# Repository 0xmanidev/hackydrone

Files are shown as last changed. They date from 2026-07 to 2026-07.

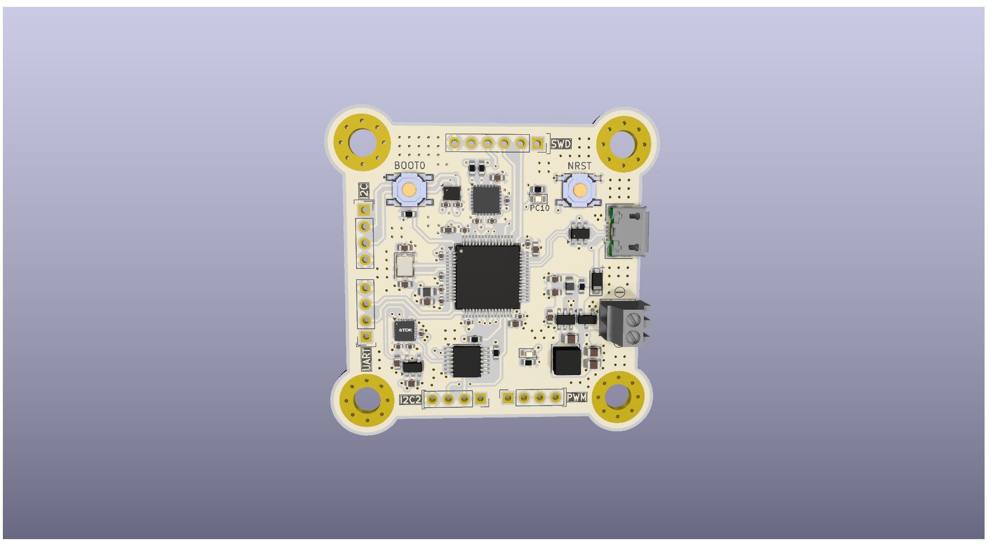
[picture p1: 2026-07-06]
pcb/flight-controller/images/pcb-front.png

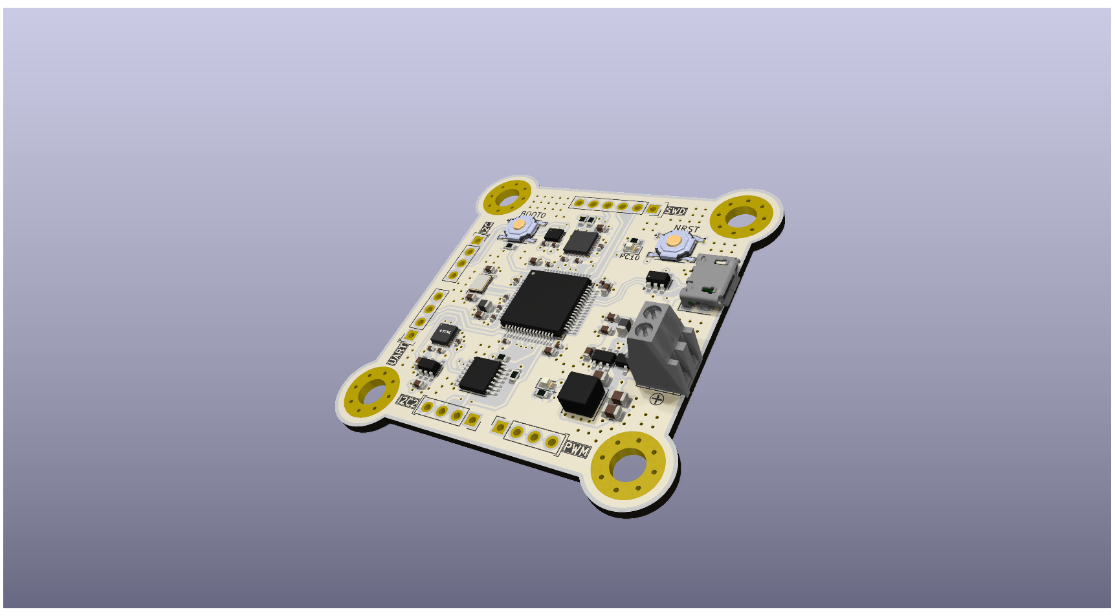
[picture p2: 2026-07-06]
pcb/flight-controller/images/pcb.png

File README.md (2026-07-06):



# HACKYDRONE
This is my project for Outpost. It's an F450-style drone with a custom-designed frame, a custom flight controller, and a strong focus on keeping costs low without sacrificing performance. The drone runs Betaflight firmware and uses a SpeedyBee ESC for reliable motor control.

This project is built with the help of Hackclub and the program submitted to
[Outpost](https://outpost.hackclub.com/) / [Stardance](https://stardance.hackclub.com/)



# Building

Clone the repository:

```bash
git clone https://github.com/0xmanidev/hackydrone.git

cd hackydrone
```

Compile firmware:

```bash
cd firmware/betaflight-2025.12.5

make TARGET=<BOARD_NAME>
```

---
## PCB

The `pcb/` directory contains everything required to manufacture the custom flight controller.

Included files:

- Complete KiCad project
- Bill of Materials (BOM)
- IPC netlist
- Manufacturing outputs

These files can be directly submitted to PCB fabrication services.


for more accurate and interactive schematics view the pcb/flight-controller -flight-controller.kicad_Sch,sensor.kicad_sch

---
# 3d model
3d-mockup

# Flight controller
pcb



# Components(these are the only after market components)
<div align="center">



</div>

---

# Current Status

| Component | Status |
|---|---|
| Frame Design | ✅ Complete |
| Flight Controller PCB | ✅ Complete |
| Firmware | ✅ Working |
| CAD Models | ✅ Complete |
| PCB Manufacturing Files | ✅ Included |
| Flight Testing | 🚧 In Progress |

---
# References

## STM32F405RGTx Microcontroller
- Datasheet:
  https://www.st.com/resource/en/datasheet/stm32f405rg.pdf
- Reference Manual (RM0090):
  https://www.st.com/resource/en/reference_manual/dm00031020.pdf
- Programming Manual:
  https://www.st.com/resource/en/programming_manual/dm00046982.pdf

---

## MPU-6050 6-Axis IMU
- Product Specification:
  https://invensense.tdk.com/wp-content/uploads/2015/02/MPU-6000-Datasheet1.pdf
- Register Map:
  https://invensense.tdk.com/wp-content/uploads/2015/02/MPU-6000-Register-Map1.pdf

---

## ICM-20948 9-Axis IMU
- Datasheet:
  https://invensense.tdk.com/wp-content/uploads/2024/03/DS-000189-ICM-20948-v1.6.pdf
- Register Map:
  https://invensense.tdk.com/wp-content/uploads/2024/03/RM-000189-ICM-20948-v1.3.pdf

---

## BMP280 Barometric Pressure Sensor
- Datasheet:
  https://cdn-shop.adafruit.com/datasheets/BST-BMP280-DS001-11.pdf

---

## AP63303WU 3A Buck Converter
- Datasheet:
  https://www.diodes.com/assets/Datasheets/AP63303_AP63357.pdf

---

## USBLC6-2SC6 USB ESD Protection
- Datasheet:
  https://www.st.com/resource/en/datasheet/usblc6-2.pdf

---

## LD39015M18R 1.8V Low Dropout Regulator
- Datasheet:
  https://www.st.com/resource/en/datasheet/ld39015.pdf

---

## NTS0104PW 4-bit Voltage Level Translator
- Datasheet:
  https://assets.nexperia.com/documents/data-sheet/NTS0104.pdf

---

## AO3401A P-Channel MOSFET
- Datasheet:
  https://aosmd.com/res/data_sheets/AO3401A.pdf

---

## TS-1187A Push Button Switch
- Datasheet:
  https://www.ckswitches.com/media/1457/ts.pdf

---

## 16 MHz Crystal Oscillator
- Example Reference (Abracon):
  https://abracon.com/Resonators/ABM3.pdf

---

## Micro USB Connector
- USB 2.0 Specification:
  https://www.usb.org/document-library/usb-20-specification

---

# Design References

- STMicroelectronics AN4488 – Getting Started with STM32F4 Hardware Development
  https://www.st.com/resource/en/application_note/dm00077036.pdf

- AN2867 – Oscillator Design Guide for STM32 Microcontrollers
  https://www.st.com/resource/en/application_note/cd00221665.pdf

- UM10204 – I²C-bus Specification and User Manual
  https://www.nxp.com/docs/en/user-guide/UM10204.pdf

- USB 2.0 Specification
  https://www.usb.org/document-library/usb-20-specification
AI USAGE : RESEARCH purposes and for mockups and visuals 

# credits : hackclub community - stasis community for helping out in making and outpost team for staying active and resolving queries
MADE with love by 0xmanidev

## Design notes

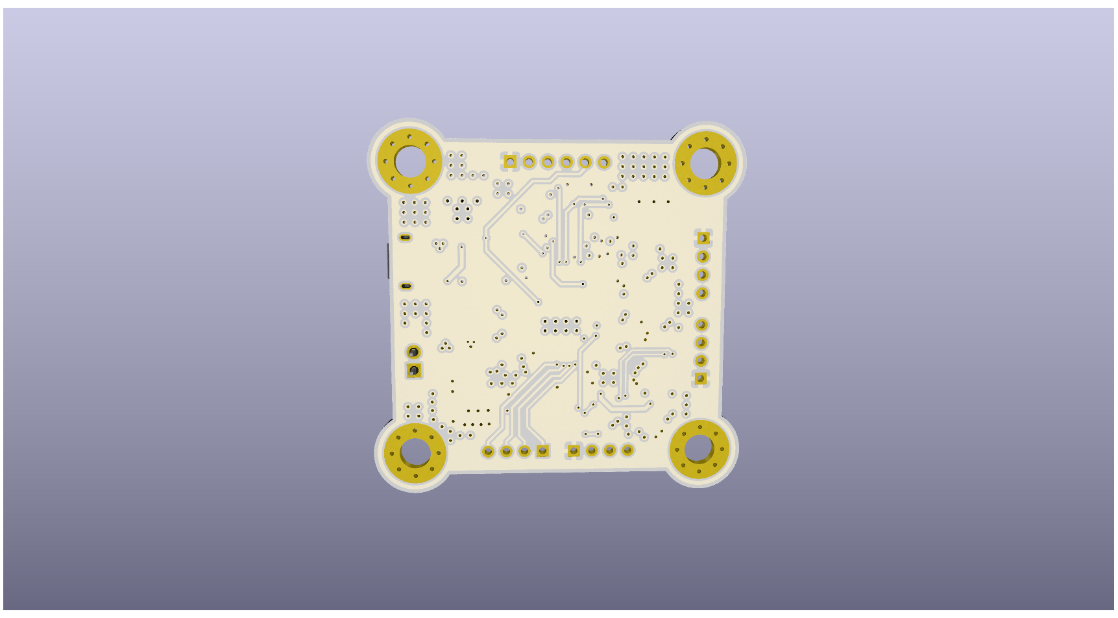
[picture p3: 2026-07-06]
pcb/flight-controller/images/pcb-back.png

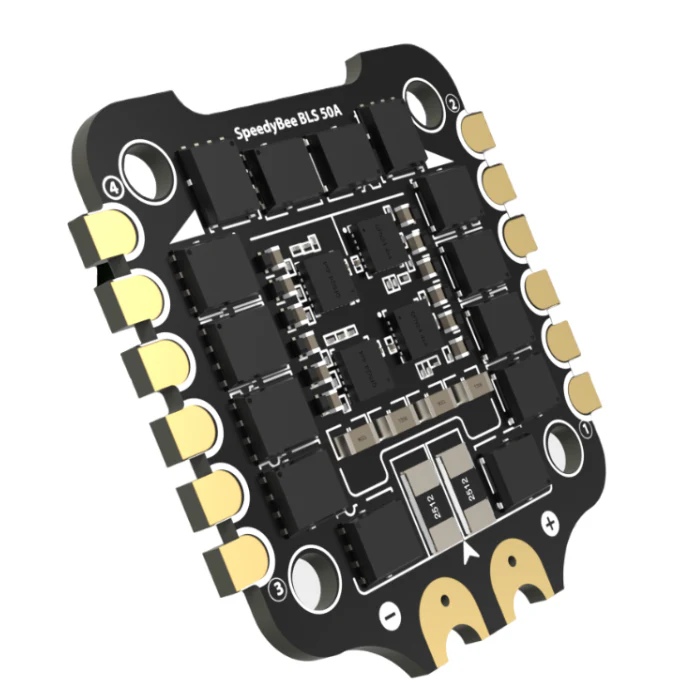
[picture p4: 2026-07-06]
pcb/ESC(only-info)/ESC-tilted.png

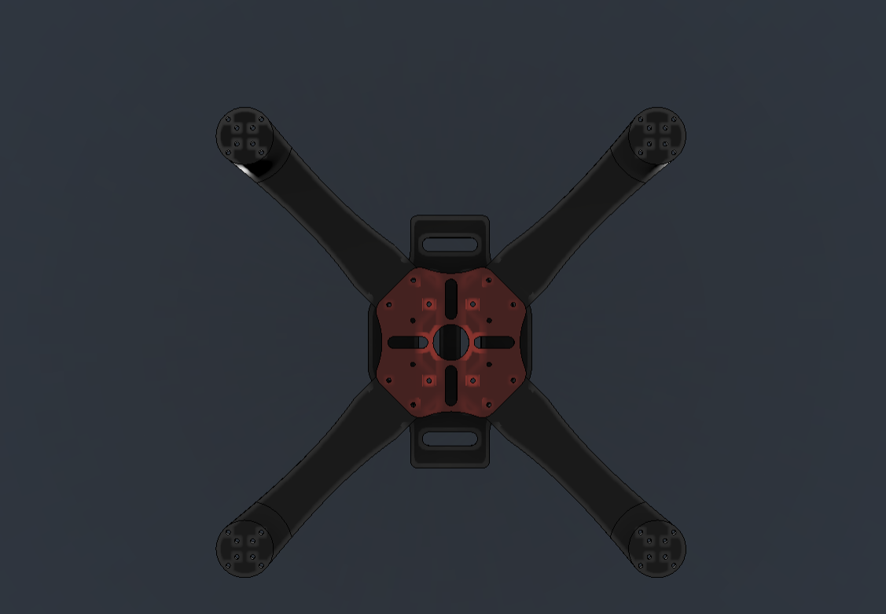
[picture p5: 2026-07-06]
cad/additional-images/top-view.png

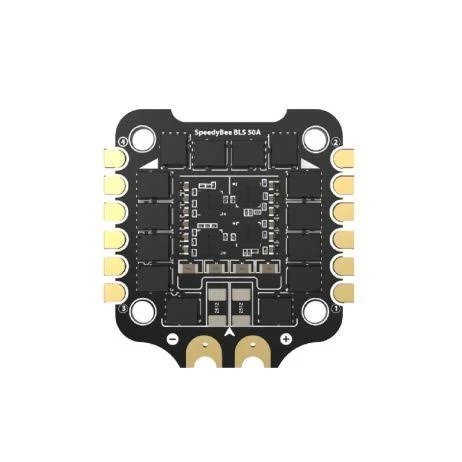
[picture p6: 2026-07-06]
pcb/ESC(only-info)/ESC.png

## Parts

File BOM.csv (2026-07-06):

Item | Category | Qty | Unit Price (USD) | Extended Price (USD) | Notes
Flight Controller (Custom) | Flight Controller | 1 | 65.00 | 65.00 | Custom FC budget indepth BOM PCB/flightcontroller
SpeedyBee BLS 50A 30x30 4-in-1 ESC | ESC | 1 | 39.00 | 39.00 | BLHeli_S 50A 3-6S
BETAFPV LiteRadio 2 SE | Radio Transmitter | 1 | 45.00 | 45.00 | ELRS version preferred
2212 920KV Brushless Motor | Motor | 4 | 10.00 | 40.00 | For 10x4.5 propellers
10x4.5 (1045) Propeller CW/CCW Pair | Propellers | 2 | 3.00 | 6.00 | Two pairs (4 props total)
4S 5200mAh LiPo Battery XT60 | Battery | 1 | 45.00 | 45.00 | 14.8V LiPo
BETAFPV ExpressLRS Nano Receiver | Receiver | 1 | 18.00 | 18.00 | 2.4GHz ELRS
XT60 Pigtail | Power | 1 | 3.00 | 3.00 | 14AWG silicone wire
1000uF 35V Low ESR Capacitor | Power Filter | 1 | 2.00 | 2.00 | Recommended for ESC
Silicone Wire (18AWG/14AWG) | Wiring | 1 | 5.00 | 5.00 | Power and signal wiring
Heat Shrink Tubing | Miscellaneous | 1 | 2.00 | 2.00 | Electrical insulation
M3 Hardware Set | Miscellaneous | 1 | 5.00 | 5.00 | Screws | standoffs | nuts
Frame (450mm class) | Frame | 1 | 25.00 | 25.00 | Compatible with 2212 motors and 10-inch props

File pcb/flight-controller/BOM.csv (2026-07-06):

Reference | Quantity | Value/Part | Description | Package
U1 | 1 | STM32F405RGTx | ARM Cortex-M4 MCU | LQFP-64
U2 | 1 | AP63203WU | 3.3V Buck Converter | TSOT23-6
U3 | 1 | USBLC6-2SC6 | USB ESD Protection | SOT23-6
U4 | 1 | MPU-6050 | 6-axis IMU | QFN-24
U5 | 1 | ICM-20948 | 9-axis IMU | QFN
U6 | 1 | LD39015M18R | 1.8V LDO | SOT-23-5
U7 | 1 | NTS0104PW | 4-bit Level Translator | TSSOP-14
U8 | 1 | BMP280 | Barometer | LGA-8
Q1 | 1 | AO3401A | P-Channel MOSFET | SOT-23
D1 | 1 | LED | Status LED | 0603
D2 | 1 | B5819W | Schottky Diode | SOD-123
D3 | 1 | LED | Power LED | 0603
F1 | 1 | Polyfuse 500mA | Resettable Fuse | 1206
FB1 | 1 | Ferrite Bead 100R | VDDA Filter | 0603
FB2 | 1 | Ferrite Bead 100R | Input Filter | 0603
L1 | 1 | 3.9uH | Shielded Inductor | SMD
Y1 | 1 | 16MHz Crystal | Crystal | 3225
S1 | 1 | TS-1187A-B-A-B | Reset Switch | SMD
S2 | 1 | TS-1187A-B-A-B | Boot Switch | SMD
J1 | 1 | Conn_01x04 | I2C Header | 2.54mm
J2 | 1 | 2-pin Screw Terminal | Power Input | 5.08mm
J3 | 1 | Conn_01x04 | I2C Header | 2.54mm
J4 | 1 | Conn_01x04 | UART Header | 2.54mm
J5 | 1 | Conn_01x04 | PWM Header | 2.54mm
J6 | 1 | Conn_01x06 | SWD Header | 2.54mm
J7 | 1 | USB Micro-B | USB Connector | SMT
H1-H4 | 4 | Mounting Hole | M3 Mounting Hole | M3
C1,C16,C17,C28,C29 | 5 | 10uF | Ceramic Capacitor | 0603/0805
C13,C14,C19,C20 | 4 | 22uF | Ceramic Capacitor | 0805/1206
C2,C3,C4,C5,C7,C8,C9,C10,C18,C21,C22,C23,C25,C26,C27,C30,C31 | 17 | 100nF | Ceramic Capacitor | 0603
C11,C12 | 2 | 10pF | Ceramic Capacitor | 0603
C15 | 1 | 2uF | Ceramic Capacitor | 0603
C24 | 1 | 2.2nF | Ceramic Capacitor | 0603
R1 | 1 | 10k | Resistor | 0603
R2,R3,R5,R6 | 4 | 2.2k | Resistor | 0603
R4,R7 | 2 | 1k | Resistor | 0603

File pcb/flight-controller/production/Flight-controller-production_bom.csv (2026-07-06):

Designator | Footprint | Quantity | Value | LCSC Part #
C1, C17, C28, C29, C9 | 0603 | 5 | 10u
C10, C2, C21, C22, C23, C25, C26, C27, C3, C30, C31, C4, C5, C6, C7, C8 | 0402 | 16 | 100n
C11, C12 | 0603 | 2 | 10p
C13, C14, C15, C16 | 0603 | 4 | 2u2
C18 | 0805 | 1 | 100n
C19, C20 | 0805 | 2 | 22u
C24 | 0603 | 1 | 2n2
D1, D3 | 0603 | 2 | LED
D2 | D_SOD-123 | 1 | b5819w
F1 | 0603 | 1 | 500 mA
FB1, FB2 | 0805 | 2 | 100R
J1, J3, J4, J5 | PinSocket_1x04_P2.54mm_Vertical | 4 | Conn_01x04
J2 | TerminalBlock_Xinya_XY308-2.54-2P_1x02_P2.54mm_Horizontal | 1 | Screw_Terminal_01x02
J6 | PinSocket_1x06_P2.54mm_Vertical | 1 | Conn_01x06
J7 | USB_Micro-B_Amphenol_10118193-0001LF_Horizontal | 1 | USB_B_Micro
L1 | L_Sunlord_SWPA4030S | 1 | 3.9uH
Q1 | SOT-23 | 1 | AO3401A
R1 | 0603 | 1 | 10k
R2, R3, R5, R6 | 0603 | 4 | 2k2
R4, R7 | 0603 | 2 | 1k
S1, S2 | SW_TS-1187A-B-A-B | 2 | TS-1187A-B-A-B
U1 | LQFP-64_10x10mm_P0.5mm | 1 | STM32F405RGTx
U2 | TSOT-23-6 | 1 | AP63203WU
U3 | SOT-23-6 | 1 | USBLC6-2SC6
U4 | InvenSense_QFN-24_4x4mm_P0.5mm | 1 | MPU-6050
U5 | InvenSense_QFN-24_3x3mm_P0.4mm | 1 | ICM-20948
U6 | SOT-23-5 | 1 | LD39015M18R
U7 | TSSOP-14_4.4x5mm_P0.65mm | 1 | NTS0104PW
U8 | Bosch_LGA-8_2x2.5mm_P0.65mm_ClockwisePinNumbering | 1 | BMP280
Y1 | Crystal_SMD_3225-4Pin_3.2x2.5mm | 1 | 16Mhz

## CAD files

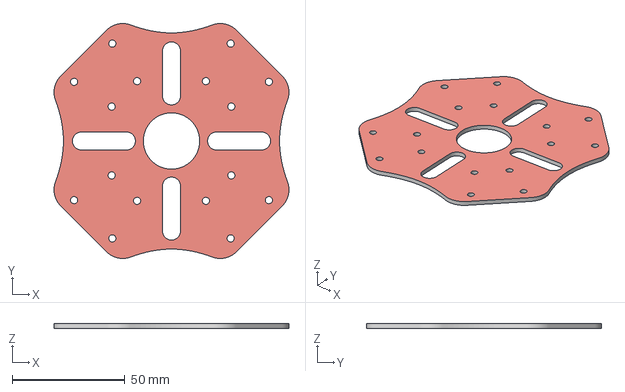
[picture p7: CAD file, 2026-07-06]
cad/3mf/top-panel.3mf
104.3 x 104.3 x 2.00 mm

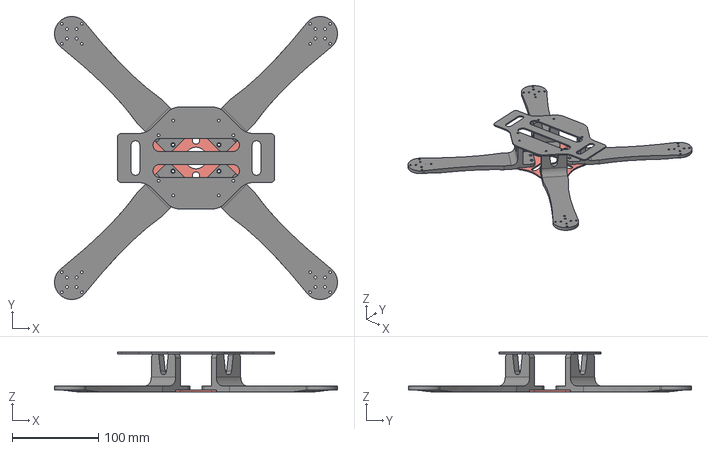
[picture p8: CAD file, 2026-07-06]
cad/drone-model.step
327.2 x 327.2 x 46.0 mm

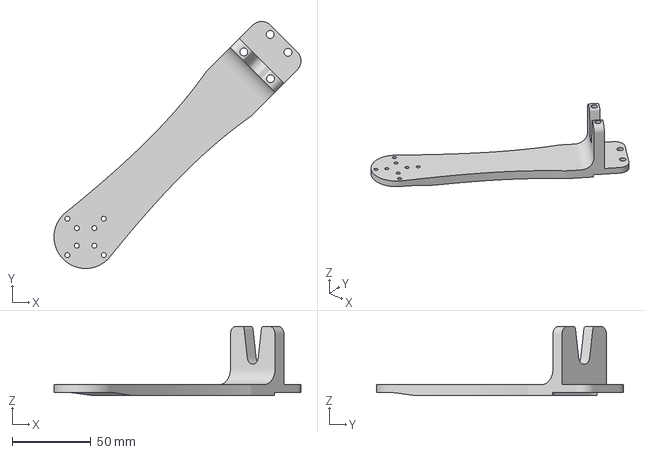
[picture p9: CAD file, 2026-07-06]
cad/3mf/arm-2.3mf
156.6 x 156.6 x 44.0 mm

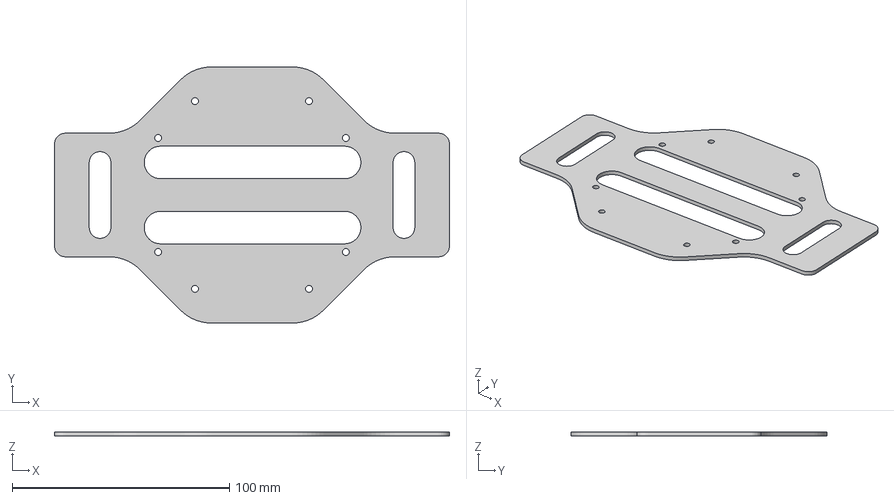
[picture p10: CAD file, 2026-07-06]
cad/3mf/bottom-panel.3mf
182.0 x 118.0 x 2.00 mm

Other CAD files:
cad/3mf/arm-4.3mf
cad/3mf/arm-3.3mf
cad/3mf/arm-1.3mf
cad/drone-model.f3d
cad/stl/arm-1.stl
cad/stl/arm-2.stl
cad/stl/arm-3.stl
cad/stl/arm-4.stl
cad/stl/bottom-panel.stl
cad/stl/top-panel.stl

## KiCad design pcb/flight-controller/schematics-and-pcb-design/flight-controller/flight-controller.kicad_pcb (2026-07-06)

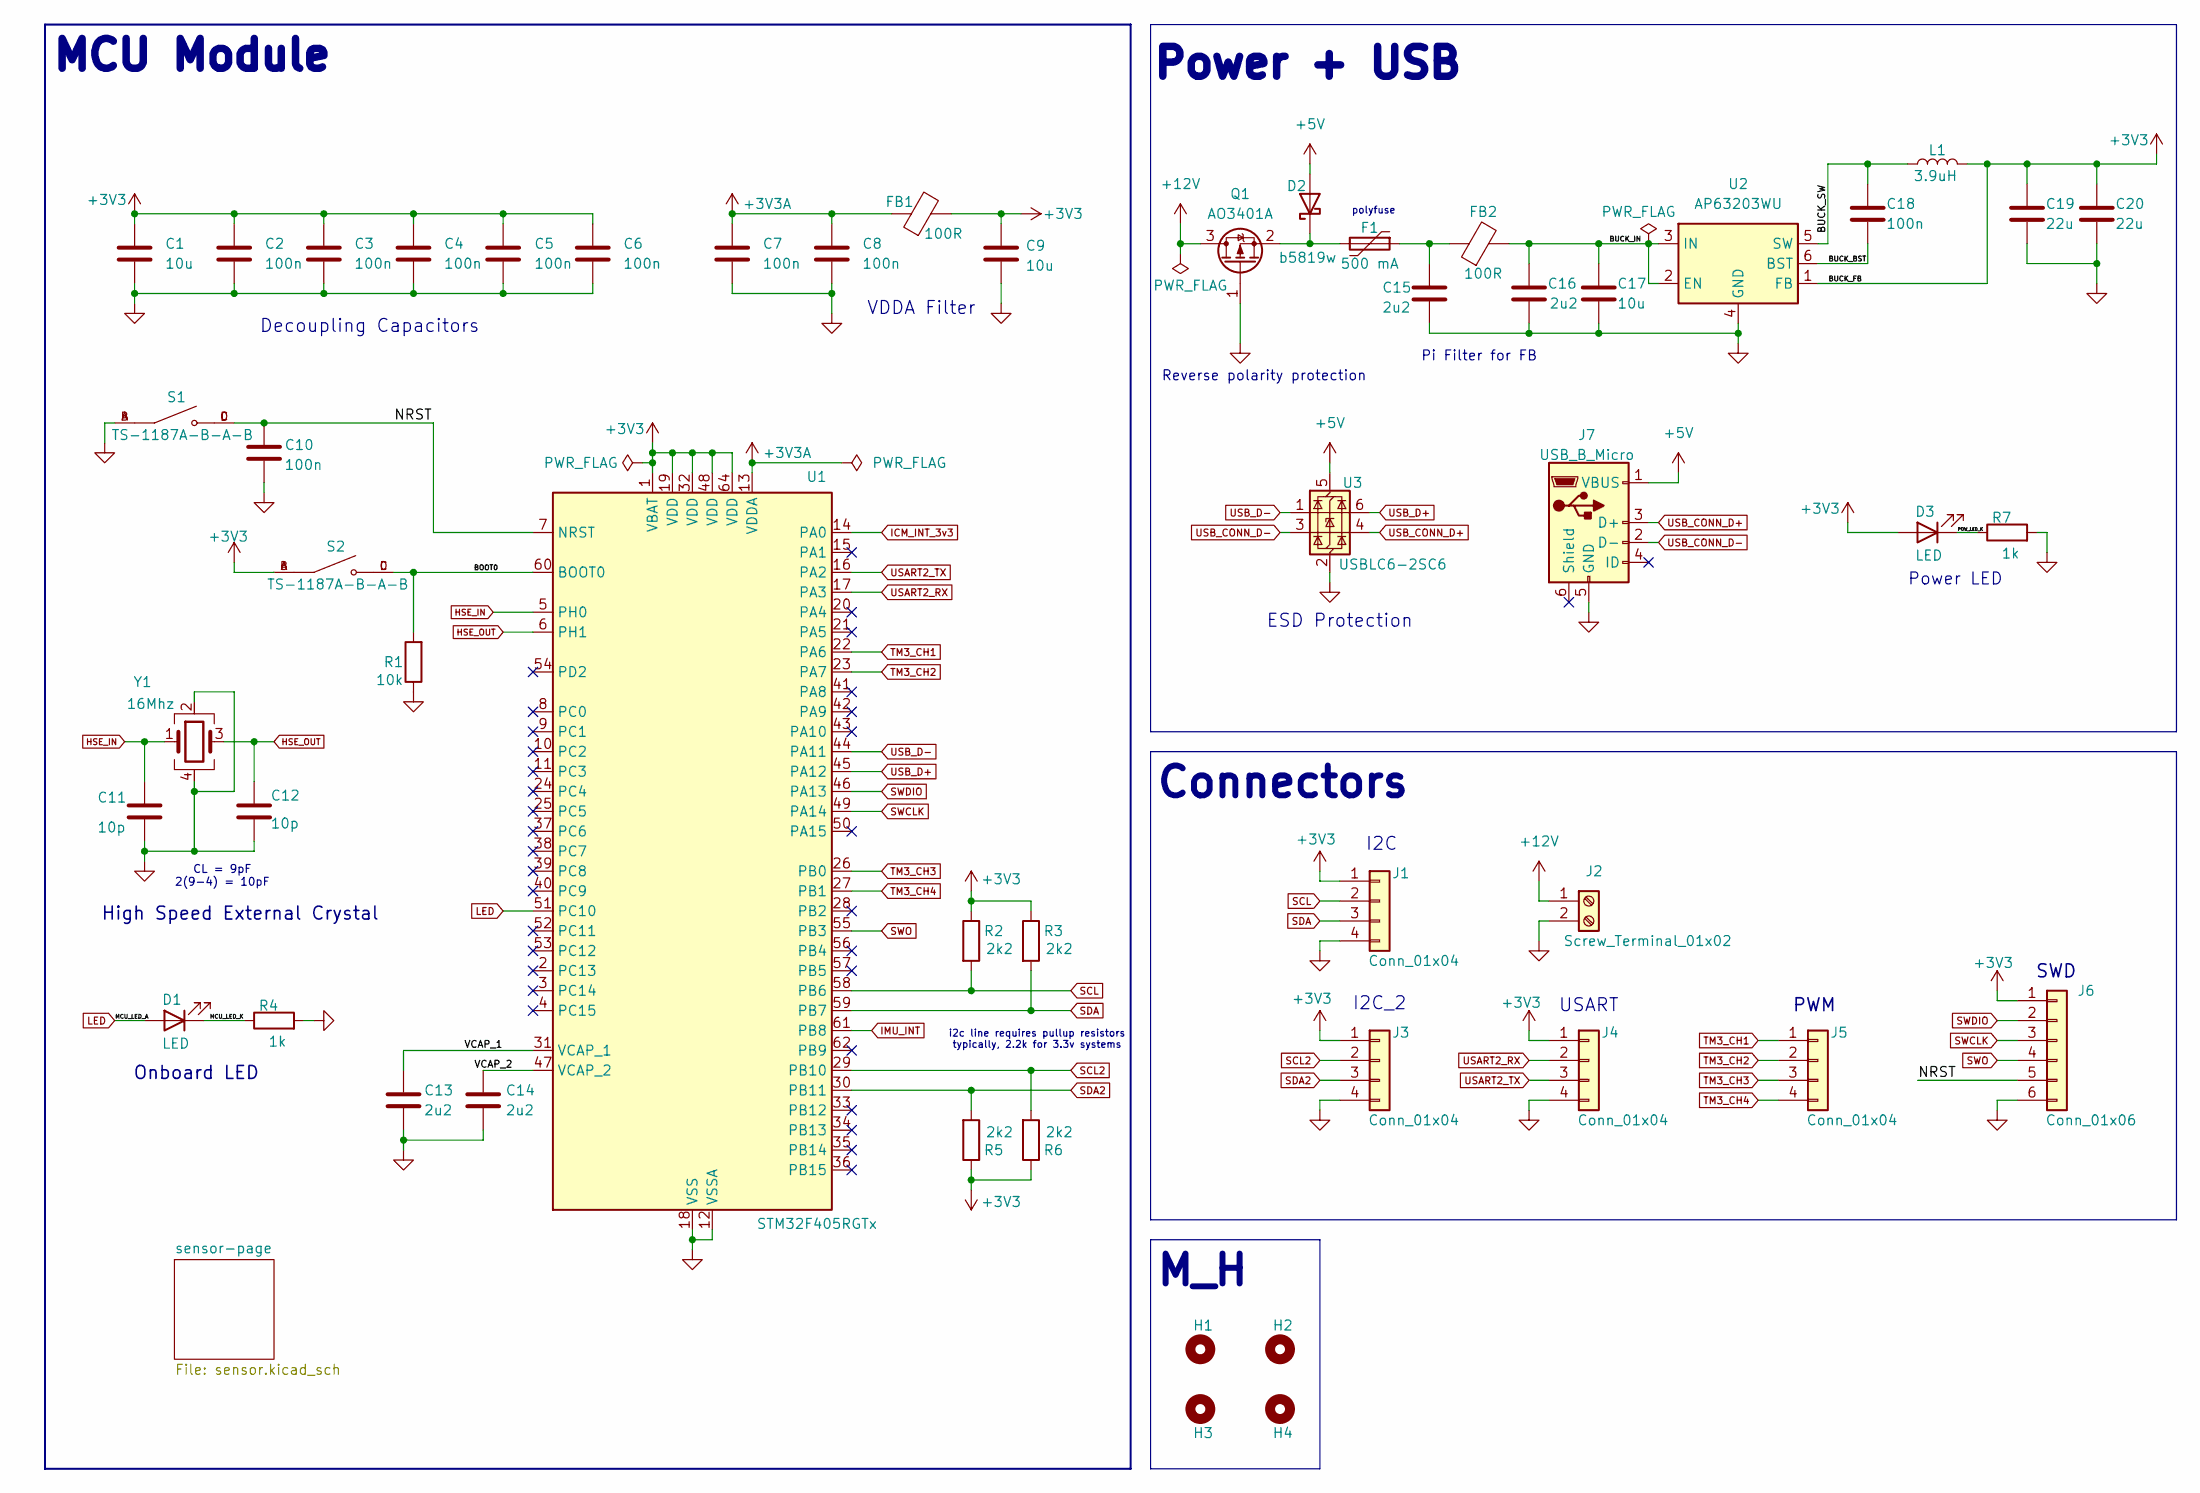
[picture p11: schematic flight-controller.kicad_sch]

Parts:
C1, C9, C17: 10u; C_0603_1608Metric
C2, C3, C4, C5, C6, C7, C8, C10: 100n; C_0402_1005Metric
C11, C12: 10p; C_0603_1608Metric
C13, C14, C15, C16: 2u2; C_0603_1608Metric
C18: 100n; C_0805_2012Metric
C19, C20: 22u; C_0805_2012Metric
D1, D3: LED; LED_0603_1608Metric
D2: b5819w; D_SOD-123
F1: 500 mA; Fuse_0603_1608Metric
FB1, FB2: 100R; L_0805_2012Metric
H1, H2, H3, H4: MountingHole; MountingHole_4.3mm_M4_Pad_Via
J1, J3, J4, J5: Conn_01x04; PinSocket_1x04_P2.54mm_Vertical
J2: Screw_Terminal_01x02; TerminalBlock_Xinya_XY308-2.54-2P_1x02_P2.54mm_Horizontal
J6: Conn_01x06; PinSocket_1x06_P2.54mm_Vertical
J7: USB_B_Micro; USB_Micro-B_Amphenol_10118193-0001LF_Horizontal
L1: 3.9uH; L_Sunlord_SWPA4030S
Q1: AO3401A; SOT-23
R1: 10k; R_0603_1608Metric
R2, R3, R5, R6: 2k2; R_0603_1608Metric
R4, R7: 1k; R_0603_1608Metric
S1, S2: TS-1187A-B-A-B; SW_TS-1187A-B-A-B; PARTREV A0
U1: STM32F405RGTx; LQFP-64_10x10mm_P0.5mm
U2: AP63203WU; TSOT-23-6
U3: USBLC6-2SC6; SOT-23-6
Y1: 16Mhz; Crystal_SMD_3225-4Pin_3.2x2.5mm

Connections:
+3V3: C1.1, C2.1, C3.1, C4.1, C5.1, C6.1, C9.1, C19.1, C20.1, D3.2 (A), FB1.2, J1.1, J3.1, J4.1, J6.1, L1.2, R2.1, R3.1, R5.1, R6.1, S2.A, S2.B, U1.1 (VBAT), U1.19 (VDD), U1.32 (VDD), U1.48 (VDD), U1.64 (VDD), U2.1 (FB); also elsewhere on the board
+3V3A: C7.1, C8.1, FB1.1, U1.13 (VDDA)
+5V: D2.2 (A), J7.1 (VBUS), U3.5 (VBUS)
+12V: J2.1, Q1.3 (D)
/STM32/BOOT0: R1.2, S2.C, S2.D, U1.60 (BOOT0)
/STM32/BUCK_BST: C18.2, U2.6 (BST)
/STM32/BUCK_IN: C16.1, C17.1, FB2.2, U2.2 (EN), U2.3 (IN)
/STM32/BUCK_SW: C18.1, L1.1, U2.5 (SW)
/STM32/MCU_LED_K: D1.1 (K), R4.1
/STM32/NRST: C10.1, J6.5, S1.C, S1.D, U1.7 (NRST)
/STM32/POW_LED_K: D3.1 (K), R7.1
/STM32/VCAP_1: C13.1, U1.31 (VCAP_1)
/STM32/VCAP_2: C14.1, U1.47 (VCAP_2)
GND: C1.2, C2.2, C3.2, C4.2, C5.2, C6.2, C7.2, C8.2, C9.2, C10.2, C11.2, C12.2, C13.2, C14.2, C15.2, C16.2, C17.2, C19.2, C20.2, H1.1, H2.1, H3.1, H4.1, J1.4, J2.2, J3.4, J4.4, J6.6, J7.5 (GND), Q1.1 (G), R1.1, R4.2, R7.2, S1.A, S1.B, U1.12 (VSSA), U1.18 (VSS), U1.63 (VSS), U2.4 (GND), U3.2 (GND), Y1.2, Y1.4; also elsewhere on the board
HSE_IN: C11.1, U1.5 (PH0), Y1.1
HSE_OUT: C12.1, U1.6 (PH1), Y1.3
ICM_INT_3v3: U1.14 (PA0); also elsewhere on the board
IMU_INT: U1.61 (PB8); also elsewhere on the board
LED: D1.2 (A), U1.51 (PC10)
unnamed: C15.1, F1.1, FB2.1
unnamed: D2.1 (K), F1.2, Q1.2 (S)
SCL: J1.2, R2.2, U1.58 (PB6); also elsewhere on the board
SCL2: J3.2, R6.2, U1.29 (PB10); also elsewhere on the board
SDA: J1.3, R3.2, U1.59 (PB7); also elsewhere on the board
SDA2: J3.3, R5.2, U1.30 (PB11); also elsewhere on the board
SWCLK: J6.3, U1.49 (PA14)
SWDIO: J6.2, U1.46 (PA13)
SWO: J6.4, U1.55 (PB3)
TM3_CH1: J5.1, U1.22 (PA6)
TM3_CH2: J5.2, U1.23 (PA7)
TM3_CH3: J5.3, U1.26 (PB0)
TM3_CH4: J5.4, U1.27 (PB1)
USART2_RX: J4.2, U1.17 (PA3)
USART2_TX: J4.3, U1.16 (PA2)
USB_CONN_D+: J7.3 (D+), U3.4 (I/O2)
USB_CONN_D-: J7.2 (D-), U3.3 (I/O2)
USB_D+: U1.45 (PA12), U3.6 (I/O1)
USB_D-: U1.44 (PA11), U3.1 (I/O1)

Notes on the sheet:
i2c line requires pullup resistors typically, 2.2k for 3.3v systems
High Speed External Crystal
PWM
MCU Module
Connectors
VDDA Filter
Power + USB
Power LED
Pi Filter for FB
SWD
USART
I2C_2
Reverse polarity protection
I2C
Onboard LED
Decoupling Capacitors
M_H
ESD Protection
polyfuse
CL = 9pF 2(9-4) = 10pF

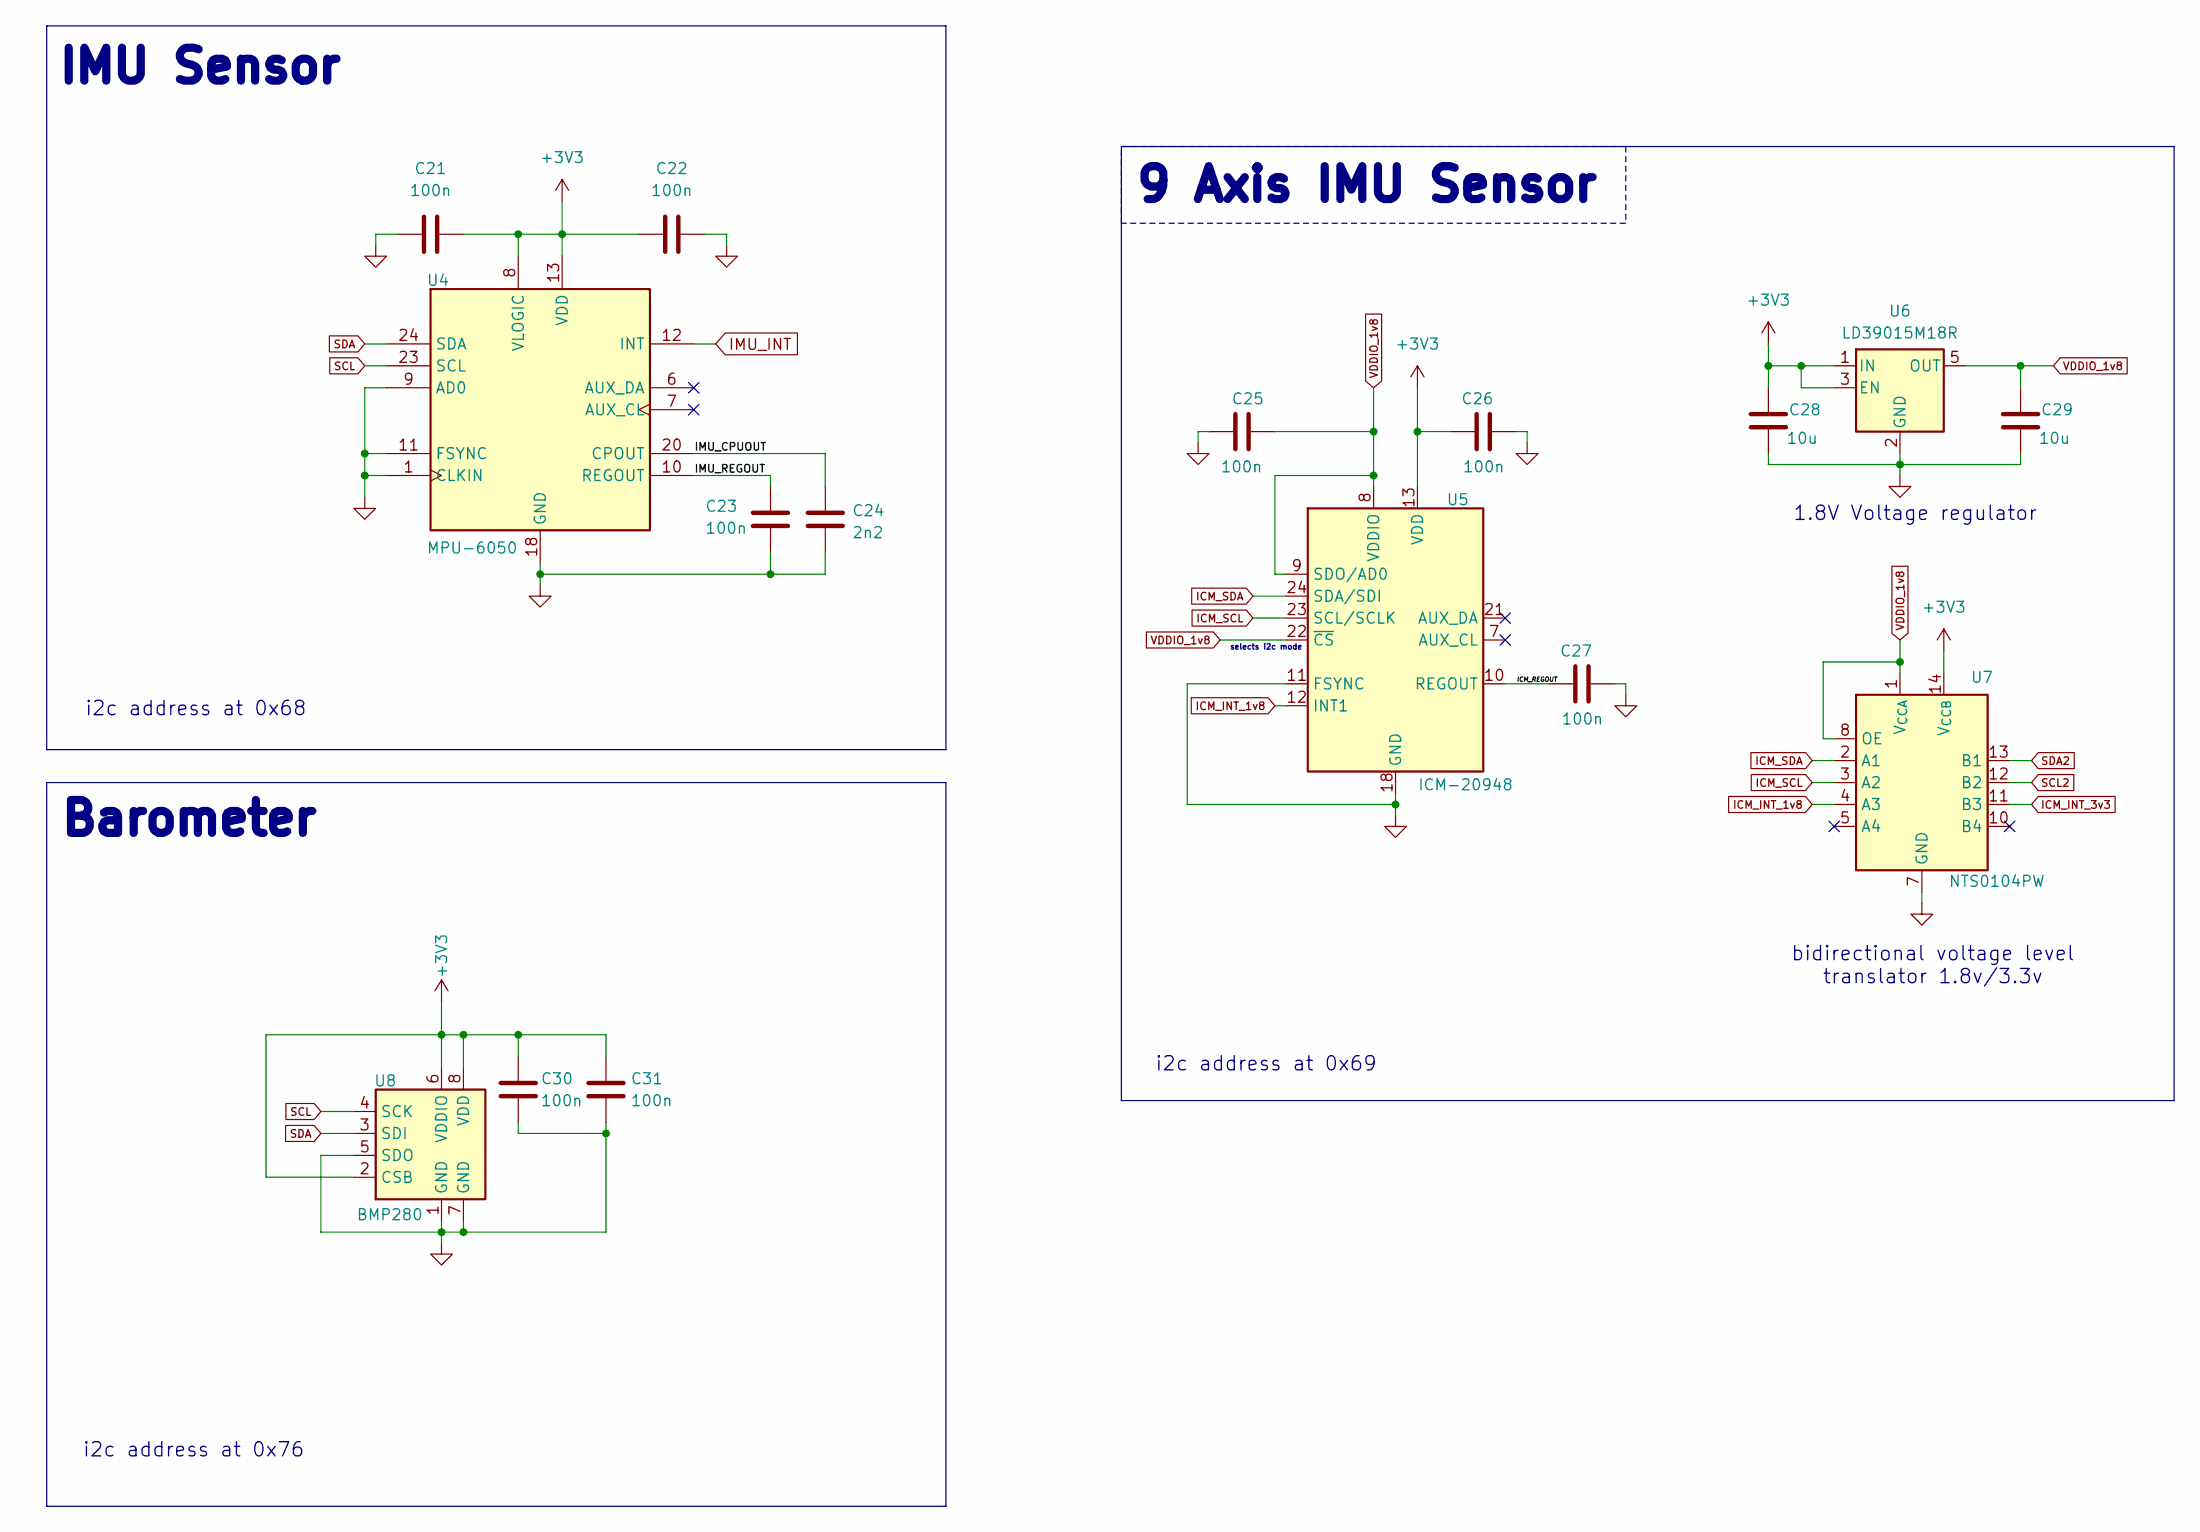
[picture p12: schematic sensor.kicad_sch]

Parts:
C21, C22, C23, C25, C26, C27, C30, C31: 100n; C_0402_1005Metric
C24: 2n2; C_0603_1608Metric
C28, C29: 10u; C_0603_1608Metric
U4: MPU-6050; InvenSense_QFN-24_4x4mm_P0.5mm
U5: ICM-20948; InvenSense_QFN-24_3x3mm_P0.4mm
U6: LD39015M18R; SOT-23-5
U7: NTS0104PW; TSSOP-14_4.4x5mm_P0.65mm
U8: BMP280; Bosch_LGA-8_2x2.5mm_P0.65mm_ClockwisePinNumbering

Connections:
+3V3: C21.2, C22.1, C26.1, C28.1, C30.1, C31.2, U4.8 (VLOGIC), U4.13 (VDD), U5.13 (VDD), U6.1 (IN), U6.3 (EN), U7.14 (V_{CCB}), U8.2 (CSB), U8.6 (VDDIO), U8.8 (VDD); also elsewhere on the board
/Sensors/ICM_REGOUT: C27.1, U5.10 (REGOUT)
/Sensors/IMU_CPUOUT: C24.1, U4.20 (CPOUT)
/Sensors/IMU_REGOUT: C23.1, U4.10 (REGOUT)
GND: C21.1, C22.2, C23.2, C24.2, C25.2, C26.2, C27.2, C28.2, C29.2, C30.2, C31.1, U4.1 (CLKIN), U4.9 (AD0), U4.11 (FSYNC), U4.18 (GND), U5.11 (FSYNC), U5.18 (GND), U5.20 (GND), U6.2 (GND), U7.7 (GND), U8.1 (GND), U8.5 (SDO), U8.7 (GND); also elsewhere on the board
ICM_INT_1v8: U5.12 (INT1), U7.4 (A3)
ICM_INT_3v3: U7.11 (B3); also elsewhere on the board
ICM_SCL: U5.23 (SCL/SCLK), U7.3 (A2)
ICM_SDA: U5.24 (SDA/SDI), U7.2 (A1)
IMU_INT: U4.12 (INT); also elsewhere on the board
SCL: U4.23 (SCL), U8.4 (SCK); also elsewhere on the board
SCL2: U7.12 (B2); also elsewhere on the board
SDA: U4.24 (SDA), U8.3 (SDI); also elsewhere on the board
SDA2: U7.13 (B1); also elsewhere on the board
VDDIO_1v8: C25.1, C29.1, U5.8 (VDDIO), U5.9 (SDO/AD0), U5.22 (~CS), U6.5 (OUT), U7.1 (V_{CCA}), U7.8 (OE)

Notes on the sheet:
Barometer
selects i2c mode
bidirectional voltage level translator 1.8v/3.3v
1.8V Voltage regulator
i2c address at 0x76
i2c address at 0x69
i2c address at 0x68
IMU Sensor
9 Axis IMU Sensor

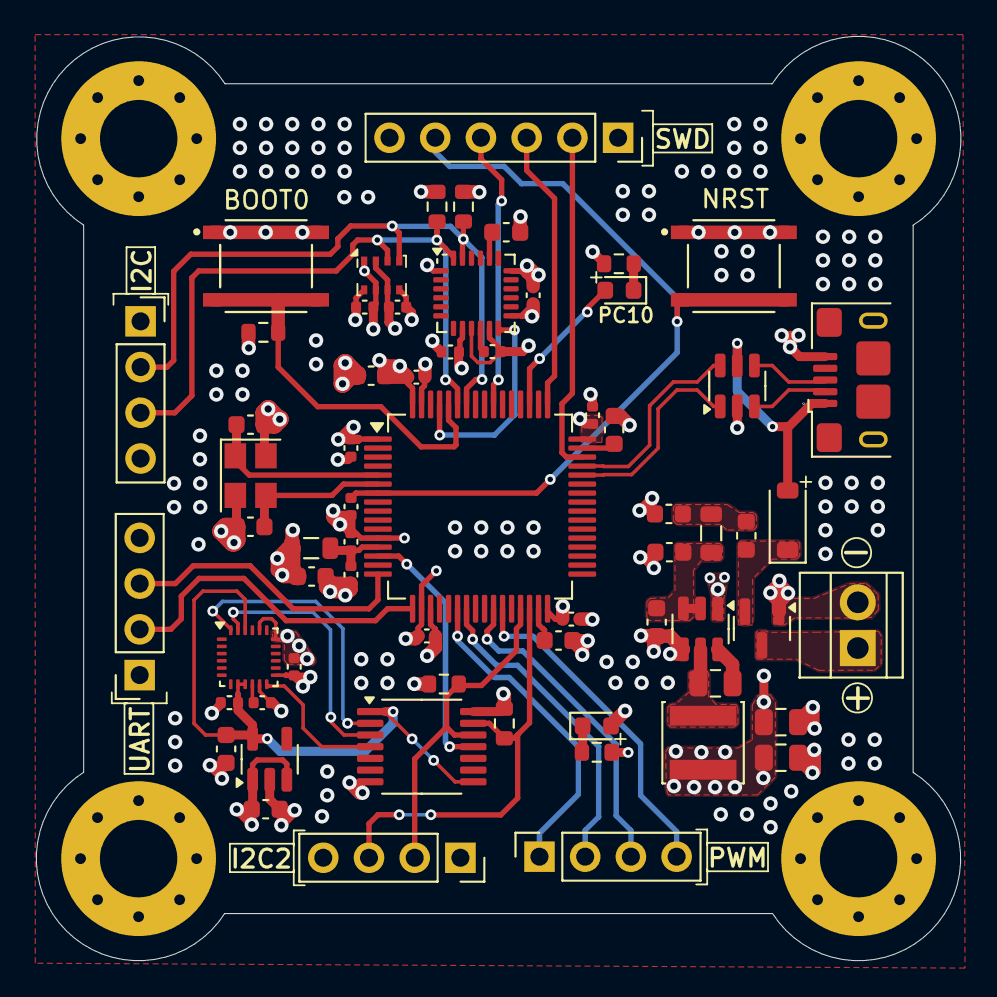
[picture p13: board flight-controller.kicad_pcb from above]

Board: 2 copper layers, 51.4 x 51.3 mm, 68 parts (0 on the bottom side), 45 nets.

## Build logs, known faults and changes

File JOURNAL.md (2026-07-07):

<!--
  This journal is auto generated by Stasis.
-->
# 04/13/2026 7 PM - Completed CAD Design

**Time spent:** 3h

I created the first complete CAD model of an F450-style drone chassis from scratch in Fusion. Instead of modifying an existing design, I modeled the frame myself while keeping the standard F450 layout in mind. After finishing the frame, I imported and positioned the major hardware components, including the motors, flight controller, power distribution board, battery, and other electronics, to verify that everything would fit properly.

This was my first serious mechanical design for a drone, so I spent a lot of time adjusting dimensions, checking clearances, and making sure the mounting holes matched the components I planned to use. Spending nearly three hours continuously working in Fusion was surprisingly exhausting, but it helped me become much more comfortable with the CAD workflow.

During this stage I also decided that, instead of buying an off-the-shelf flight controller, I would design my own from scratch. That decision significantly increased the scope of the project, but it also made it much more educational.

## Images



---

# 06/11/2026 2 PM - Started the Schematics

**Time spent:** 2h

I began designing the custom flight controller by selecting the main microcontroller and planning the overall hardware architecture. Before placing components, I researched multiple options for sensors, regulators, connectors, communication interfaces, and supporting circuitry to understand which parts would best fit the design.

Using that research, I created the first draft of the schematic. At this stage, the focus was on connecting the major functional blocks rather than perfecting every detail. The draft gave me a solid foundation to continue refining the design.

## Images



---

# 06/12/2026 2 PM - Finished the Schematics

**Time spent:** 4h

I completed the full schematic for the flight controller by adding the remaining components and verifying all of the electrical connections. This included integrating the MCU, IMU, power regulation circuitry, USB interface, SWD programming header, oscillator, connectors, and the required passive components.

After assembling the complete schematic, I carefully reviewed the connections against the datasheets to catch mistakes before moving on to PCB layout. Completing the schematic was a major milestone because it transformed the design from a concept into a board that could actually be routed.

## Images



---

# 06/14/2026 2 PM - Started the PCB

**Time spent:** 0.5h

I started the PCB layout by importing the schematic into KiCad and defining the physical board outline. Since the flight controller was designed specifically for my drone frame, I based the edge cuts and mounting hole locations directly on the CAD model created earlier.

I also began arranging the major components on the board while considering mounting constraints, connector accessibility, and keeping related circuitry close together. Although this session was short, it established the mechanical foundation for the rest of the PCB design.

## Images



---

# 06/21/2026 - 07/01/2026 - Finished the PCB

**Time spent:** 8h

Most of the PCB work happened over several shorter sessions instead of one long sitting, so I combined them into a single journal entry.

I completed the entire PCB layout by placing every component, routing the power and signal traces, creating ground pours, and continuously refining the design. Since this was my first complex PCB, I encountered several routing challenges and design mistakes along the way. I frequently asked experienced PCB designers for feedback, which helped me improve component placement, routing strategies, and overall board quality.

Throughout the process I repeatedly ran design rule checks, fixed issues that appeared during routing, and adjusted the layout to make the board easier to manufacture and assemble. These reviews taught me a lot about practical PCB design beyond what tutorials usually cover.

I paused development on July 1 to focus on my exams before returning to finish the remaining work.

## Images



---

# 07/05/2026 - 07/06/2026 - Finalizing

**Time spent:** 2h

After my exams, I returned to the project to complete the final cleanup. I fixed several remaining issues in the Power Distribution System (PDS), made final adjustments to the flight controller, and verified that the design met all of the project requirements.

Once the remaining issues were resolved, I submitted the completed design for review and successfully received X-tier approval to proceed on this projecy. Reaching this stage marked the completion of both the mechanical and electronic design work, leaving the project ready for manufacturing and assembly.

## Images



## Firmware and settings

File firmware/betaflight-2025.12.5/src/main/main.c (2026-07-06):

/*
 * This file is part of Cleanflight and Betaflight.
 *
 * Cleanflight and Betaflight are free software. You can redistribute
 * this software and/or modify this software under the terms of the
 * GNU General Public License as published by the Free Software
 * Foundation, either version 3 of the License, or (at your option)
 * any later version.
 *
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
 * If not, see <http://www.gnu.org/licenses/>.
 */

#include <stdbool.h>
#include <stdint.h>

#include "platform.h"

#ifdef USE_VCP
#include "drivers/serial_usb_vcp.h"
#endif

#include "drivers/system.h"

#include "fc/init.h"

#ifdef USE_MULTICORE
#include "platform/multicore.h"
#include "usb/usb_cdc.h"
#endif

#ifdef USE_USB_MSC
#include "drivers/usb_msc.h"
#endif

#include "scheduler/scheduler.h"

void run(void);

int main(int argc, char * argv[])
{
#ifdef USE_MAIN_ARGS
    targetParseArgs(argc, argv);
#else
    UNUSED(argc);
    UNUSED(argv);
#endif

#if SERIAL_PORT_COUNT > 0
    printfSerialInit();
#endif

    // Do basic system initialisation including multicore support if applicable
    systemInit();

#ifdef USE_MULTICORE
    // Perform early initialisation prior to USB
    multicoreExecuteBlocking(initPhase1);

    // Now perform the core initialisation
    multicoreExecuteBlocking(initPhase2);
#else
    initPhase1();
    initPhase2();
#endif

#ifdef USE_USB_MSC
    mscButtonInit();
    if (checkMsc()) {
        // MSC mode TODO: boot using single core
        initMsc();
        // Never returns (but just in case...)
        return 0;
    }
#endif

#ifdef USE_VCP
    // initialise the USB CDC interface using core 0 all USB code, including
    // interrupts, must run on core 0
    usbVcpInit();
#endif

#ifdef USE_MULTICORE
    // Now perform the final initialisation
    multicoreExecuteBlocking(initPhase3);
#else
    initPhase3();
#endif

    // Launch the scheduler
    run();

    return 0;
}

void FAST_CODE run(void)
{
    while (true) {
        scheduler();
#if defined(RUN_LOOP_DELAY_US) && RUN_LOOP_DELAY_US > 0
        delayMicroseconds_real(RUN_LOOP_DELAY_US);
#endif
    }
}

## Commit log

2026-07-06 exclude things in gitignore
    [BOM.csv, Flight-controller-production_bom.csv, Flight-controller-production_designators.csv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]
2026-07-06 Update README with interactive schematics information
    Added a note for interactive schematics in the README.
2026-07-06 Update README with component references and design resources
    Added references and design resources for various components including microcontrollers, sensors, and other electronic parts.
2026-07-06 Update JOURNAL.md with project milestones
    Documented progress on CAD design, schematics, PCB layout, and finalization of the flight controller.
2026-07-06 Create BOM.csv with project components and prices
    Added a Bill of Materials (BOM) for the project.
    [BOM.csv]
2026-07-07 Revise JOURNAL.md with project progress details
    Updated journal entries with detailed descriptions of CAD design, schematic creation, and PCB layout for a custom flight controller project.
